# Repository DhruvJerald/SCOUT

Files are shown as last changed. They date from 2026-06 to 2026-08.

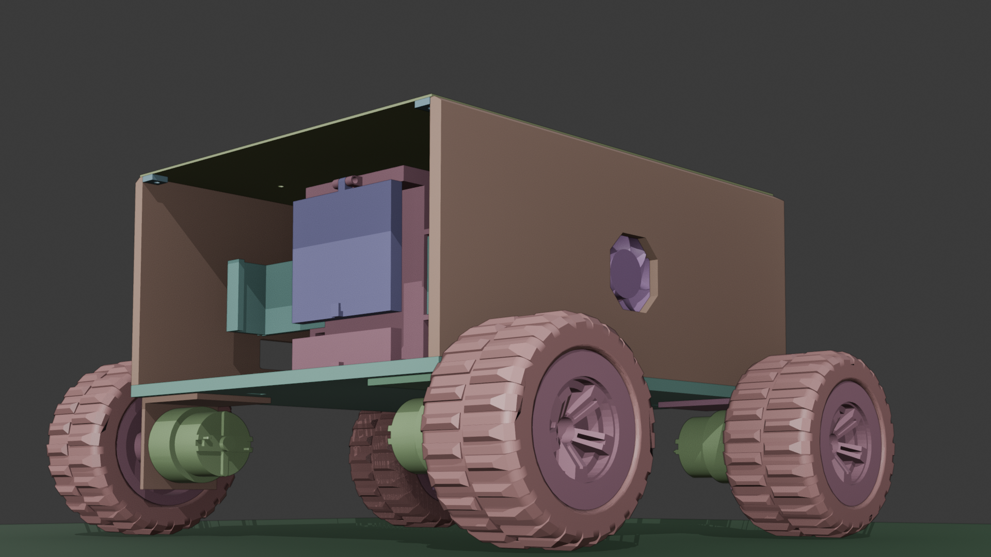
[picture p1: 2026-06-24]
BLENDER/rover.png

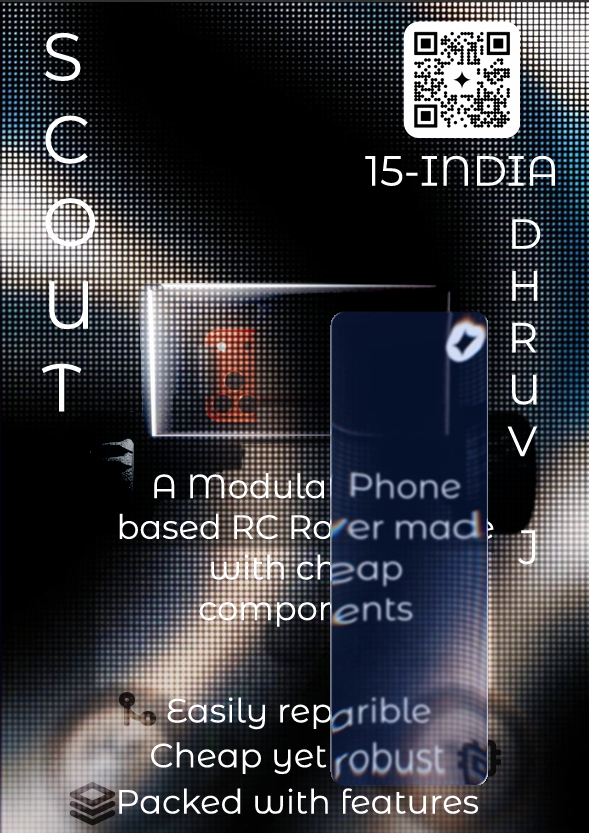
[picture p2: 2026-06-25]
Zine/Zine.png

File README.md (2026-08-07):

<div align="center">

# SCOUT
rover-removebg-preview

**A Rover built from cheap and easily available parts**

---

rover render

</div>

---

## What is it?

It's a RC rover that can be controlled from nearly everywhere. The idea follows a phone mounted in the chassis that does the heavy lifting such as streaming video, providing GPS, accelerometer, gyroscope, and cellular data while the ESP32 handles motors, sensors, and near Realtime control.
The entire rover has M3 mounting holes all over and doesn't use and glues or zip ties to make the final project closer to a product than a mere prototype and also being 3D printed in PLA.

## Why did i make it?
I really liked the idea of using the phones IMU, Accelerometer, GPS, Cellular connectivity, Camera, Microphone, Speakers, Flashlight and the onboard CPU of a phone which is really compact and possess a lot of expensive features of a real rover which would cost a fortune to source individual parts and i wanted to build a rover at a fraction of the price

---

## Goals

- **Repairable first** — Should be easy to make changes(spacious), Should be easy to mount things (M3 mounts), Should allow for future additions (Future proof with additional GPIO extensions)
- **Phone as compute** — SIM, Camera, GPS, IMU, Microphone, Speaker, Display, Accelerometer (All from a cheap android)
- **Cheap and sourceable** — every component available on Amazon.in or Robu.in or can be salvaged from old electronics
- **Controllable from anywhere but maintain fastest connectivity** — (fastest connection is made) between WIFI-AP, 4G cellular and Bluetooth

---

---

## Design



---

## Schematic

schematic

---

## BOM 

## BOM  

| Item | Price (INR) | Price (USD) |
|---|---|---|
| ESP32 DevKit V1 | 409 | $4.40 |
| 7.4V 6000mAh 2S LiPo | 1199 | $12.70 |
| XT60 connector pair | 260 | $2.75 |
| Rocker switch | 45 | $0.48 |
| LM2596 buck converter | 98 | $1.04 |
| TB6612FNG × 2 | 249 | $2.64 |
| INA219 | 275 | $2.92 |
| SSD1306 OLED | 329 | $3.50 |
| 5V brushless fan | 180 | $1.91 |
| AO3400A MOSFET | 84 | $0.89 |
| Resistors (10kΩ + 100Ω) | 154 | $1.63 |
| Capacitors (1000µF + 100µF × 2 + 0.1µF × 2) | 247 | $2.61 |
| M3 screw kit | 360 | $3.81 |
| 12V 200RPM motors × 4 | 500 | $5.29 |
| DHT22 | 160 | $1.69 |
| JST-XH connectors | 109 | $1.15 |
| 18AWG silicone wire | 300 | $3.17 |
| 85mm wheels × 4 | 749 | $7.93 |
| M3 standoffs | 300 | $3.17 |
| Perfboard | 125 | $1.32 |
| Phone mount (rubber bands) | 150 | $1.59 |
| 2S LiPo charger | 676 | $7.16 |
| White PLA 1kg | 899 | $9.51 |
| **Total** | **~₹7,875** | **~$85** |

> Many of these :- capacitors, resistors, perfboard, fan, MOSFET — >can be salvaged from old electronics.

---

## Features
- Battery saver mode — shuts down OLED, Fan, other non crucial sensors
- live voltage, current, and power from INA219 
- temperature data to keep control of overheating within the rover 
- status display on SSD1306 OLED
- all telemetry streamed to PC/Phone dashboard (web dashboard)

**Expansion**

The chassis has mounting holes and an I2C header for adding modules without redesigning anything so any future extension can be connected to the extension port and the new code could be compiled to work with it

---
## Assembly instructions

1)Gather all components listed in the BOM and a Android device with a working SIM card with cellular connection

2)3D print all the parts from https://github.com/DhruvJerald/SCOUT/tree/956e7d2e782e086f435cfa4e5dd025103bdec9e7/3D%20Prints and assemble it with M3 screws 

3)Add the Perfboard and the Electronics to the enclosure with M3 standoffs

4)Wire it according to the schematic https://github.com/DhruvJerald/SCOUT/blob/956e7d2e782e086f435cfa4e5dd025103bdec9e7/Schematic_Rover.png

5)Upload the firmware to the ESP (Not current one as its AI made and purely for proof of concept and not to be used in the final build)

6)Set up VPS on PC side

7)run the code on both devices 

---

## Images



chassis render

second render

SIDE







---

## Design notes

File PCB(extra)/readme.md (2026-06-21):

well uhh i idk why i created a pcb for it for no reason dont ask why i didnt i think of a perfboard or a mount earlier because thats what i ended up doing

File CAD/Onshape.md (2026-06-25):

Onshape Project link:- https://cad.onshape.com/documents/bb327acbee40f2ee69b4a73d/w/27bea1cc711a9dabe8ca095b/e/9c1c2f5421d70ceec33e618a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

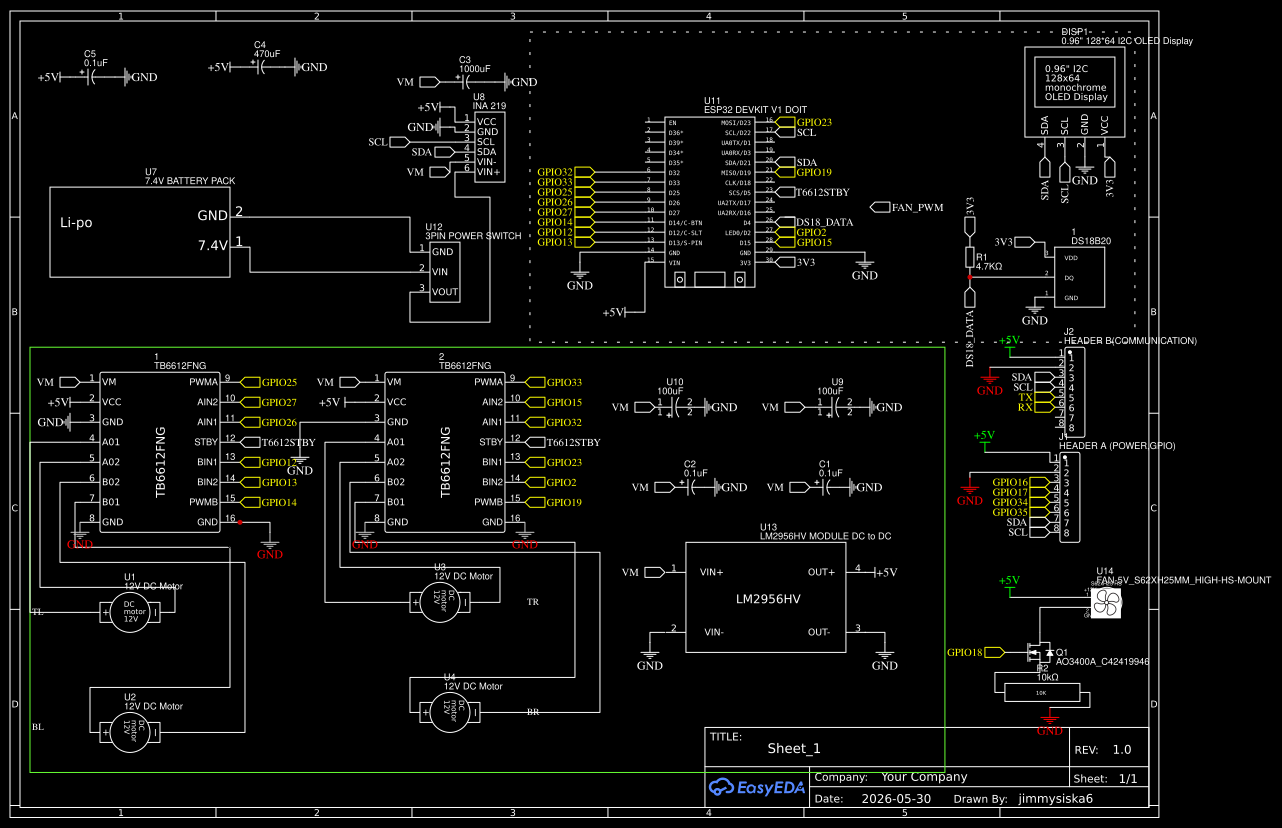
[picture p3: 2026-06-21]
Schematic_Rover.png

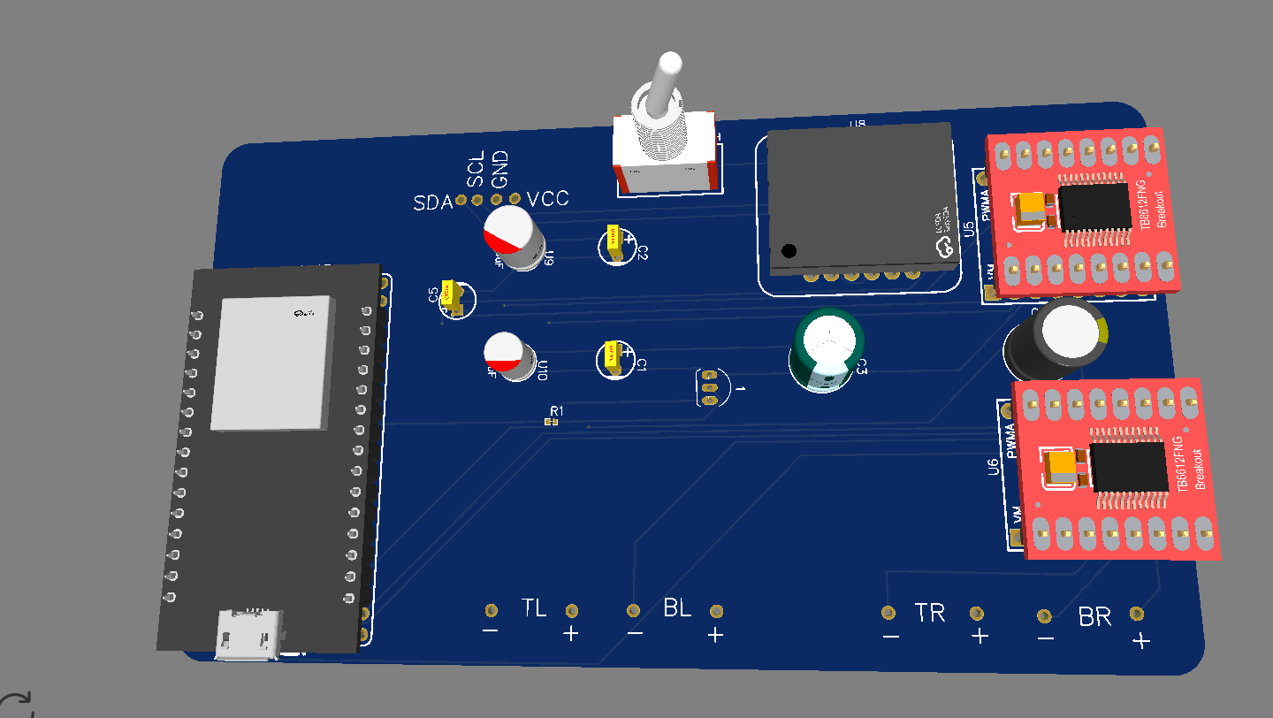
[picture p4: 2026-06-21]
PCB(extra)/Screenshot 2026-05-31 172008.png

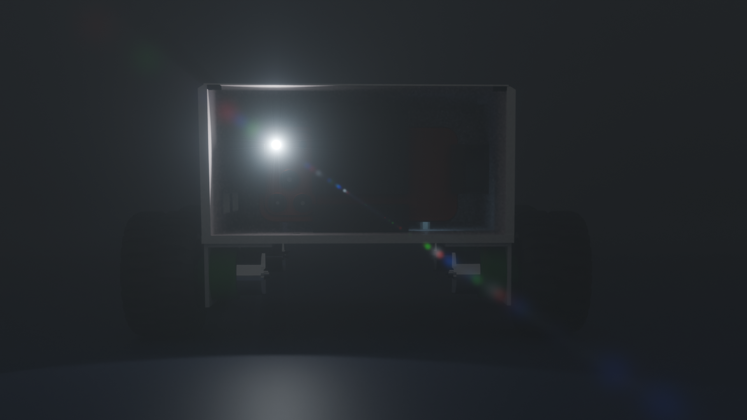
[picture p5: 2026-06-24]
BLENDER/Front view.png

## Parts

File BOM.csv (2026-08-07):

Category | Item | Qty | Notes/Specs | Seller Link | Price (INR) | Price (USD)
Main Controller | ESP32 DevKit V1 | 1 | DevKit V1 | https://robu.in/product/esp-wroom-32-wifi-bluetooth-networking-smart-component-development-board/ | ₹409 | $4.40
Power | 7.4V 6000mAh 2S LiPo | 1 | With BMS | https://robu.in/product/pro-range-nmc-18650-7-4v-6000mah-3c-2s2p-li-ion-battery-pack/ | ₹1199 | $12.70
Power | XT60 connector pair | 1 | Male+Female | https://www.amazon.in/Robocraze-XT60-Connector-Pair/dp/B07Q7VZ716/ | ₹260 | $2.75
Power | Rocker switch ≥5A | 1 | Toggle type | https://www.amazon.in/Rocker-Switch-Toggle-Plastic-Electronics/dp/B0GWS1MJB6/ | ₹45 | $0.48
Power | LM2596 Buck Converter | 1 | 7.4V→5V | https://www.amazon.in/LM2596-DC-DC-Buck-Converter-Module/dp/B009P04YTO/ | ₹98 | $1.04
Motor Drivers | TB6612FNG | 2 | Dual driver | Robu Services | ₹249 | $2.64
Monitoring | INA219 | 1 | Current sensor | https://www.amazon.in/xcluma-INA219-I2C-Bi-Directional/dp/B07YNQSLKX/ | ₹275 | $2.92
Monitoring | SSD1306 OLED 0.96 inch | 1 | I2C OLED | https://www.amazon.in/Robocraze-Semiconductor-Accessory-Display/dp/B07Q7VZ716/ | ₹329 | $3.50
Cooling | 5V brushless fan (30–40mm) | 1 | Exhaust fan | https://www.amazon.in/Electronic-Spices-40x40x10mm-Brushless-Exhaust/dp/B0BC8FLML8/ | ₹180 | $1.91
Cooling | AO3400A MOSFET | 1 | Logic-level | https://www.amazon.in/AO3400-30V-5-8A-N-Channel-Mosfet/dp/B09VH1K4GW/ | ₹84 | $0.89
Cooling | 10kΩ resistor | 1 | Gate pulldown | https://www.amazon.in/10K-ohm-Watt-Resistor-Tolerance/dp/B09VH1K4GW/ | ₹74 | $0.78
Capacitors | 1000µF 16V electrolytic | 1 | Main rail | https://www.amazon.in/gp/product/B08X2PGPPV/ | ₹89 | $0.94
Capacitors | 100µF 16V electrolytic | 2 | TB6612 rails | https://www.amazon.in/100uF-16V-Electrolytic-Capacitor/dp/B0F5MYTYQ3/ | ₹79 | $0.83
Capacitors | 0.1µF ceramic | 2 | TB6612 rails | https://www.amazon.in/0-1uF-104-Ceramic-Capacitor-Pack/dp/B0F5MYTYQ3/ | ₹79 | $0.83
Hardware | M3 Screw Kit | 1 set | Assorted sizes | https://www.amazon.in/gp/product/B0FQWLQMXV/ | ₹360 | $3.81
DRIVE | 12V geared DC Motor | 4 | 12V 200 RPM | https://www.amazon.in/D-V-12V-200-RPM-Geared-Motor/dp/B07YNQSLKX/ | ₹500 | $5.29
Cooling | DHT22 temp+humidity sensor | 1 | Fan controls | https://www.amazon.in/AM2302-Temperature-Humidity-Sensor-Module/dp/B0CXMJH34D/ | ₹160 | $1.69
Resistors | 100Ω resistor | 1 | Pull-up | https://www.amazon.in/100-Ohm-Resistor-Pack/dp/B09VH1K4GW/ | ₹80 | $0.85
Wires | JST-XH connectors | 4 | Battery connectors | https://www.amazon.in/Electronic-Spices-Connector-2-5mm-Female/dp/B0BKWDKB1W/ | ₹109 | $1.15
Wires | 18AWG silicone wire | 1m | High durability | https://www.amazon.in/gp/product/B09VLDN5LN/ | ₹300 | $3.17
DRIVE | 85mm Wheels | 4 | Wheels | https://www.amazon.in/INVENTO-Plastic-Robotic-Durable-Rubber/dp/B07YNQSLKX/ | ₹749 | $7.93
Hardware | M3 standoffs | 20 | Standoffs | https://www.amazon.in/gp/product/B07T34Q6G6/ | ₹300 | $3.17
Hardware | 12×8 Perfboard | 1 | Prototype board | https://www.amazon.in/xcluma-Double-Copper-Prototype-Universal/dp/B073DF2CB9/ | ₹125 | $1.32
Phone Mount | Rubber Bands | 3 | Holds phone | https://www.amazon.in/cart/smart-wagon/ | ₹150 | $1.59
Charger | 2S Li-ion charger | 1 | For battery | https://robu.in/product/lithium-battery-charger-8-4v-1a-with-dc-plug-2-indicators/ | ₹676 | $7.16
Chassis | White PLA 1kg | 1 | Printed for chassis | https://www.amazon.in/WOL-3D-Filament-Improved-Formula/dp/B08D6N1HHK/ | ₹899 | $9.51
TOTAL |  |  |  |  | ₹7857 | $85

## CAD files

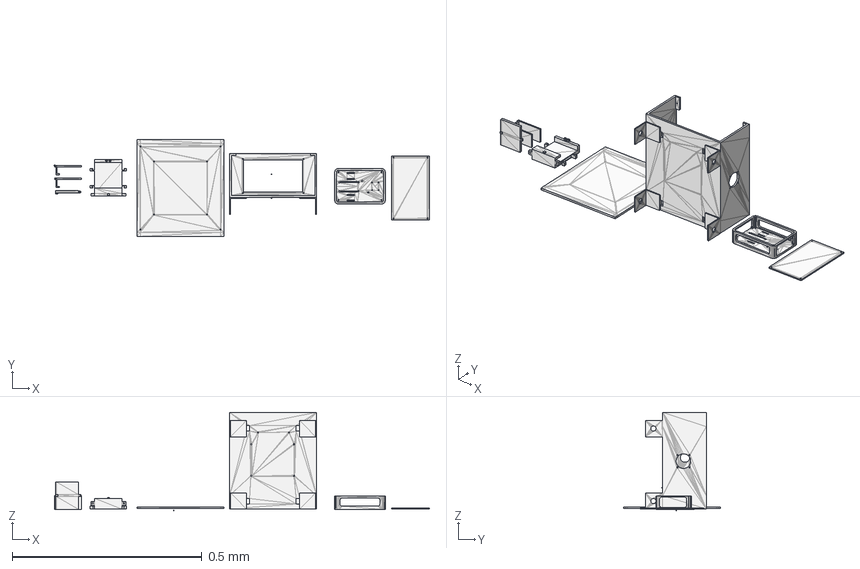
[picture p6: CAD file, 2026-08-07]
3D Prints/CHASIS.step
0.989 x 0.255 x 0.26 mm

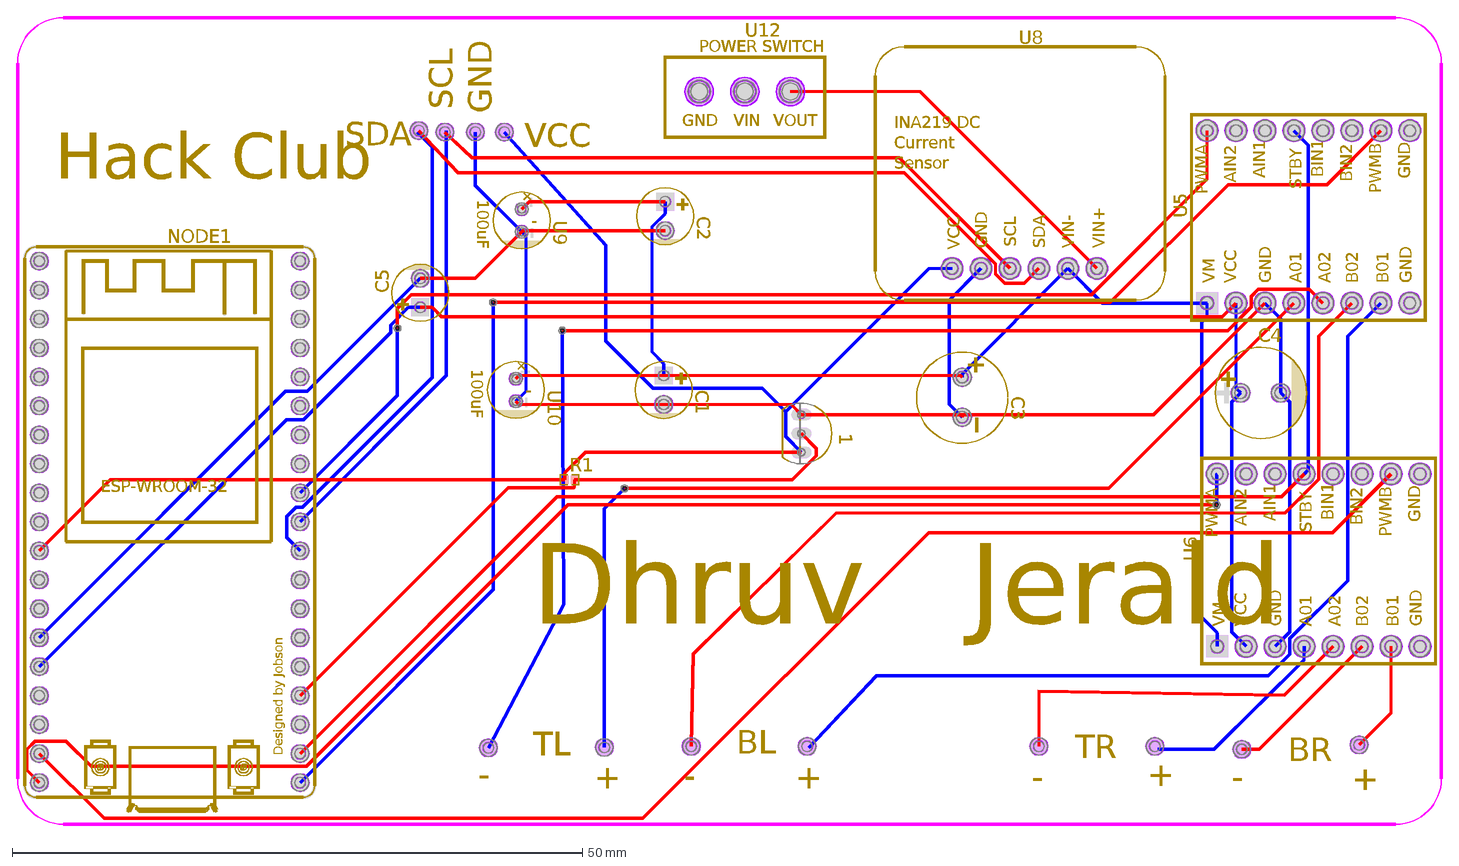
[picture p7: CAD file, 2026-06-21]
PCB(extra)/PCB_Rover-Scheme1_2026-06-01.dxf
BR
TR
BL
TL
+
-
VCC
SDA
GND
SCL
Hack Club
Dhruv Jerald
1
NODE1
ESP-WROOM-32
Designed by Jobson
R1
U5
B02
A02
VM
PWMA
AIN2
AIN1
STBY
BIN1
BIN2
PWMB
B01
A01
U6
U8
VIN+
VIN-
INA219 DC
Current
Sensor
U9
100uF
U10
U12
VIN
VOUT
POWER SWITCH
C1
C2
C5
C3
C4

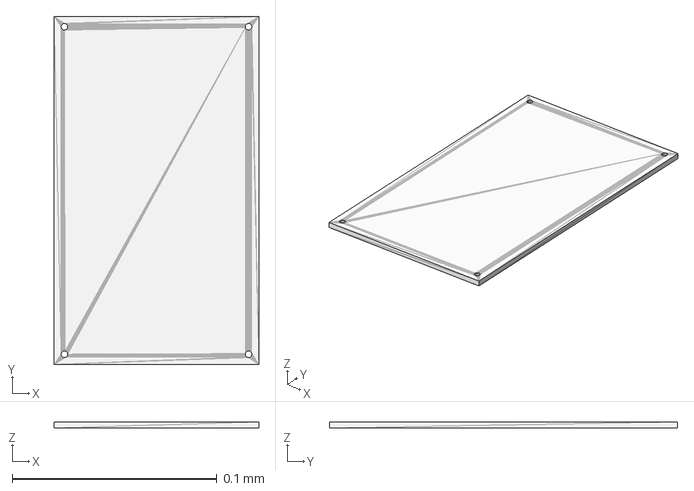
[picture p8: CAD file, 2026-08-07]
3D Prints/BACKPLATE (TP).step
0.1 x 0.17 x 0.003 mm

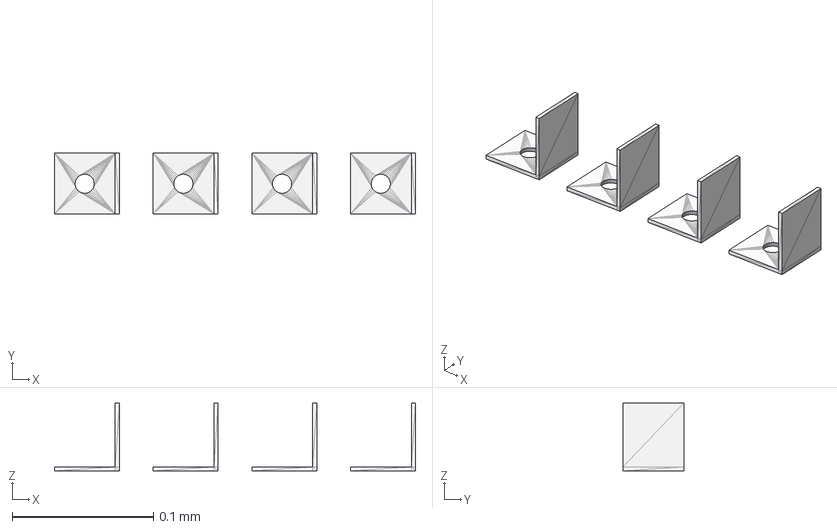
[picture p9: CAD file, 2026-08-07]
3D Prints/MOTOR MOUNTS.step
0.256 x 0.0431 x 0.0482 mm

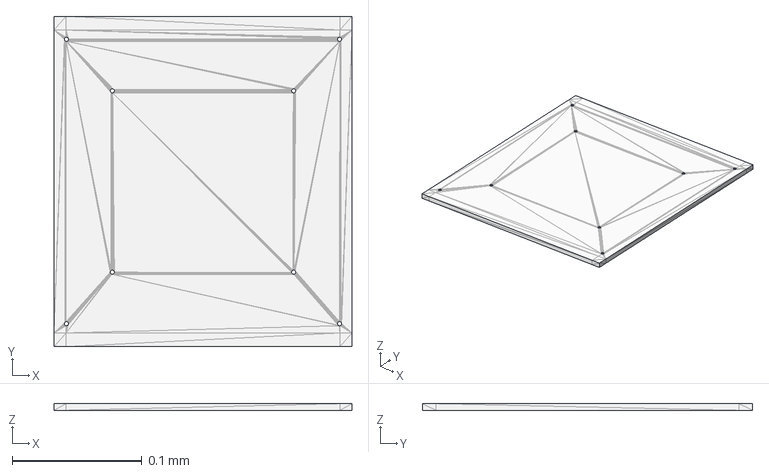
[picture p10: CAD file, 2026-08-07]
3D Prints/ROOF.step
0.23 x 0.255 x 0.00512 mm

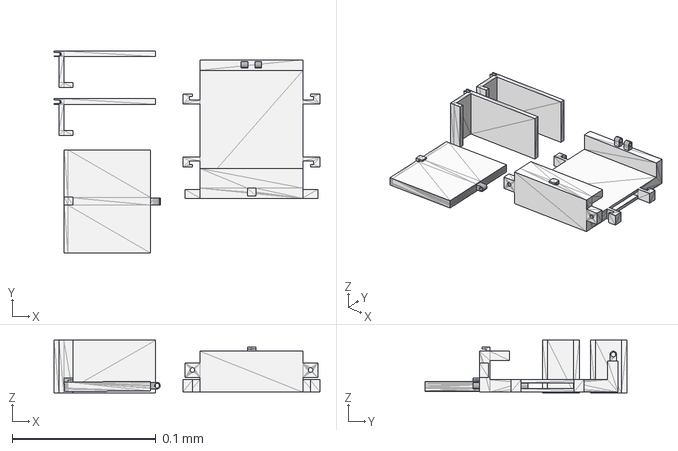
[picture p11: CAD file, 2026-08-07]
3D Prints/PHONE MOUNTS.step
0.185 x 0.14 x 0.0366 mm

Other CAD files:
3D Prints/BACKPLATE (TP).stl
3D Prints/CHASIS.stl
3D Prints/MOTOR MOUNTS.stl
3D Prints/PHONE MOUNTS.stl
3D Prints/ROOF.stl

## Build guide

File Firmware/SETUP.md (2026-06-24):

THIS FIRMWARE ISNT TESTED YET

# SCOUT SETUP FILE

---

## Contents

1. System Architecture
2. Hardware Architecture
3. Power Architecture
4. Pin Assignment and Wiring
5. Transport Layer Architecture
6. Software Architecture
7. Firmware Setup (ESP32)
8. Phone Dashboard Setup
9. VPS Relay Setup
10. Battery Saver Mode
11. Communication Protocol Reference
12. Build and Test Sequence
13. Fault Diagnosis

---

## 1. System Architecture

The system has three physical nodes. Every command and every telemetry reading
travels through all three in sequence.

```
+------------------+        internet         +------------------+
|    PC (home)     |  <--------------------> |   VPS (cloud)    |
|                  |     WebSocket / HTTPS   |   cloud_relay.js |
|  Browser opens   |                         |   public IP      |
|  phone/index.html|                         |  Node.js server  |
+------------------+                         +--------+---------+
                                                      |
                                                   4G / WiFi
                                                      |
                                             +--------v---------+
                                             |  Phone (on rover)|
                                             |  Chrome browser  |
                                             |  index.html      |
                                             |                  |
                                             |  Holds TWO       |
                                             |  connections:    |
                                             |  1. outward VPS  |
                                             |  2. inward ESP32 |
                                             +--------+---------+
                                                      |
                                          BLE or WiFi (last mile)
                                                      |
                                             +--------v---------+
                                             |  ESP32 (rover)   |
                                             |  BLE UART server |
                                             |  WiFi AP server  |
                                             |  WebSocket server|
                                             +--------+---------+
                                                      |
                                              GPIO pins (wires)
                                                      |
                              +-----------+-----------+-----------+
                              |           |           |           |
                        +-----v----+ +----v----+ +----v---+ +----v----+
                        | TB6612 1 | |TB6612 2 | | INA219 | |DS18B20 |
                        | L motors | |R motors | | power  | | temp   |
                        +-----+----+ +----+----+ +--------+ +--------+
                              |           |
                       +------+    +------+
                       |           |
                  +----v----+ +----v----+
                  |LF motor | |RF motor |
                  |LR motor | |RR motor |
                  +---------+ +---------+
```

The phone is the bridge. It is physically mounted on the rover and runs the
browser app. It maintains one connection outward (to VPS or PC) and one
connection inward (to ESP32 via BLE or WiFi). When you push the joystick on
your PC, the command travels: PC -> VPS -> phone -> ESP32 -> motors.

When the phone and rover are close to your PC on the same network, the VPS
is bypassed entirely. When the phone is within 10m of the ESP32 and BLE is
available, WiFi is bypassed as well. The system always takes the shortest path.

---

## 2. Hardware Architecture

```
                    ROVER PHYSICAL LAYOUT (top view)
    +-------------------------------------------------------+
    |  [OLED display]                    [Expansion header] |
    |                                                        |
    |   +---------------+     +---------------+             |
    |   |   TB6612 #1   |     |   TB6612 #2   |             |
    |   |  (left side)  |     |  (right side) |             |
    |   +---+-----------+     +----------+----+             |
    |       |                            |                   |
    |  LF--LR                        RF--RR                 |
    |  motors                        motors                  |
    |                                                        |
    |   +---------------------------+                        |
    |   |       ESP32 DevKit V1     |   [INA219]             |
    |   |                           |   [DS18B20]            |
    |   +---------------------------+                        |
    |                                                        |
    |   [Fan + AO3400 MOSFET]          [Power switch]        |
    |                                                        |
    |   +---------------------------+                        |
    |   |  2x 18650 cells + 2S BMS |                        |
    |   +---------------------------+                        |
    +-------------------------------------------------------+
    [LF wheel]  [LR wheel]           [RF wheel]  [RR wheel]

    LAYER STACK (electronics, bottom to top)

    Bottom plate:  4 motors, wheels, motor mounts
    Middle plate:  18650 cells, BMS, power switch, INA219
    Top plate:     ESP32, TB6612 x2, DS18B20, fan
    Roof rail:     OLED, expansion header, phone mount
```

---

## 3. Power Architecture

The INA219 sits in series on the positive rail so it measures total current
drawn by the entire system. The LM2596 buck converter steps 7.4V down to 5V
for the ESP32 and logic. The TB6612 drivers receive the raw battery voltage
directly as their motor supply.

```
  2x 18650 cells (7.4V nominal, 8.4V full, 6.0V cutoff)
         |
         |  positive rail
         v
     [2S BMS]  <-- cuts off if cell < 3.0V or current > rated limit
         |
         v
    [1N5408 diode]  <-- reverse polarity protection, 0.6V drop
         |
         v
     [3A fuse]  <-- overcurrent protection (motor short circuit)
         |
         v
  [Power switch]
         |
         +---------------------------+
         |                           |
         v                           v
     [INA219]                  [LM2596 buck]
    VIN+ to VIN-               7.4V --> 5V
    measures all                    |
    system current                  +----------+----------+
         |                          |          |          |
         v                          v          v          v
    [TB6612 VM]               [ESP32 VIN]  [OLED VCC]  [Fan 5V]
    raw 7.4V for                3.3V reg    (3.3V)     (5V)
    motors                      onboard
         |
    +----+----+
    |         |
    v         v
 [TB6612 #1] [TB6612 #2]
 LF + LR     RF + RR
 motors      motors

  VOLTAGE AT EACH POINT (measure with multimeter to verify)

  Point                    Expected range      If wrong
  -------                  --------------      --------
  Battery terminals        6.0 - 8.4V          BMS tripped or dead cells
  After diode              0.6V less than bat   Diode missing or reversed
  After fuse               same as post-diode   Fuse blown
  INA219 VIN+ to VIN-      < 0.1V (shunt drop) INA219 bypassed (wrong wire)
  TB6612 VM                same as post-fuse    Break in motor supply wire
  LM2596 output            4.8 - 5.2V          Buck not adjusted or failed
  ESP32 VIN                4.8 - 5.2V          Wire break to ESP32
  ESP32 3.3V pin           3.1 - 3.4V          ESP32 internal reg failed
```

### Current budget

```
  Component                Idle      Active (peak)
  ---------                ----      -------------
  ESP32 (WiFi active)      150mA     350mA
  ESP32 (BLE only)          30mA      80mA
  OLED SSD1306              20mA      20mA
  INA219                     1mA       1mA
  DS18B20                    1mA       1mA
  Fan (5V, small)             0mA     200mA
  4x TT motors (idle)        20mA      20mA
  4x TT motors (running)       --     800mA
  4x TT motors (stall)         --    2000mA
  -------------------------------------------------------
  Normal mode total          200mA   ~2600mA peak
  Battery saver total         50mA   ~2100mA (motors only)

  Runtime estimate (5000mAh 2S LiPo):
    Driving normally:  ~1.5 - 2.5 hours
    Battery saver idle:  ~50 hours (BLE connected, stationary)
```

---

## 4. Pin Assignment and Wiring

### ESP32 DevKit V1 pinout map

Only the pins used in this project are labeled. Blank pins are free for
expansion unless marked NEVER USE.

```
                    ESP32 DevKit V1 (38-pin)
                    +=========================+
               3.3V |  1                  38 | GND
              RESET |  2                  37 | GPIO23  --> R_F_PWMA  (LEDC ch2)
    NEVER  --> GND  |  3                  36 | GPIO22  --> I2C SCL
    USE         5V  |  4                  35 | GPIO21  --> I2C SDA
                    |  5                  34 | GPIO19  --> R_R_BIN1
   INPUT      GPIO34|  6                  33 | GPIO18  --> R_R_PWMB  (LEDC ch3)
   ONLY       GPIO35|  7                  32 | GPIO5   --> R_R_BIN2
   (no        GPIO32|  8 --> R_F_AIN1    31 | GPIO17  RESERVED TX2
   pullup)    GPIO33|  9 --> TB6612 STBY 30 | GPIO16  RESERVED RX2
              GPIO25| 10 --> L_F_AIN1    29 | GPIO4   --> DS18B20 data
              GPIO26| 11 --> L_F_AIN2    28 | GPIO2   --> R_F_AIN2
              GPIO27| 12 --> L_F_PWMA    27 | GPIO15  --> Fan gate
              GPIO14| 13 --> L_R_BIN1    26 | GPIO13  --> L_R_PWMB  (LEDC ch1)
              GPIO12| 14 --> L_R_BIN2    25 | GPIO12  already used (left)
    NEVER  --> GND  | 15                  24 | GND
    USE    --> 3.3V | 16                  23 | 5V (from LM2596)
    GPIO6-11 FLASH  |  (internal, never break out)
                    +=========================+

    PINS TO NEVER USE:
    GPIO 0   -- Boot button. Pulling LOW during boot enters flash mode.
    GPIO 1   -- UART TX (USB serial debug output)
    GPIO 3   -- UART RX (USB serial debug input)
    GPIO 6-11-- Connected to internal flash memory. Using these destroys flash.
    GPIO34-39-- INPUT ONLY. No internal pull-up. Cannot drive anything.

    RESERVED (do not assign):
    GPIO16   -- Future UART2 RX (GPS module)
    GPIO17   -- Future UART2 TX (GPS module)
```

### Full wiring table

```
  ESP32 GPIO   Direction   Connects to           Notes
  ----------   ---------   -----------           -----
  GPIO2        OUT         TB6612#2 AIN2         R Front motor dir B
  GPIO4        IN          DS18B20 DATA          4.7k pullup to 3.3V required
  GPIO5        OUT         TB6612#2 BIN2         R Rear motor dir B
  GPIO12       OUT         TB6612#1 BIN2         L Rear motor dir B
  GPIO13       OUT(PWM)    TB6612#1 PWMB         L Rear speed, LEDC ch1
  GPIO14       OUT         TB6612#1 BIN1         L Rear motor dir A
  GPIO15       OUT         AO3400 gate           Fan MOSFET, 100R series + 10k pulldown
  GPIO18       OUT(PWM)    TB6612#2 PWMB         R Rear speed, LEDC ch3
  GPIO19       OUT         TB6612#2 BIN1         R Rear motor dir A
  GPIO21       IN/OUT      SDA bus               INA219 + OLED shared, 4.7k pullup
  GPIO22       IN/OUT      SCL bus               INA219 + OLED shared, 4.7k pullup
  GPIO23       OUT(PWM)    TB6612#2 PWMA         R Front speed, LEDC ch2
  GPIO25       OUT         TB6612#1 AIN1         L Front motor dir A
  GPIO26       OUT         TB6612#1 AIN2         L Front motor dir B
  GPIO27       OUT(PWM)    TB6612#1 PWMA         L Front speed, LEDC ch0
  GPIO32       OUT         TB6612#2 AIN1         R Front motor dir A
  GPIO33       OUT         TB6612#1 STBY         Shared STBY for both TB6612s
```

### TB6612 motor driver wiring (per chip)

Each TB6612 has two independent H-bridge channels (A and B), each driving
one motor. The chip needs 3 pins per motor (direction A, direction B, PWM)
plus one shared STBY pin.

```
  TB6612 #1 (left side)          TB6612 #2 (right side)
  +-----------------+            +-----------------+
  | VM   --> bat+   |            | VM   --> bat+   |
  | GND  --> GND    |            | GND  --> GND    |
  | VCC  --> 3.3V   |            | VCC  --> 3.3V   |
  | STBY --> GPIO33 |            | STBY --> GPIO33 |  (shared)
  |                 |            |                 |
  | AIN1 --> GPIO25 |            | AIN1 --> GPIO32 |
  | AIN2 --> GPIO26 |            | AIN2 --> GPIO2  |
  | PWMA --> GPIO27 |            | PWMA --> GPIO23 |
  | AO1  --> LF+    |            | AO1  --> RF+    |
  | AO2  --> LF-    |            | AO2  --> RF-    |
  |                 |            |                 |
  | BIN1 --> GPIO14 |            | BIN1 --> GPIO19 |
  | BIN2 --> GPIO12 |            | BIN2 --> GPIO5  |
  | PWMB --> GPIO13 |            | PWMB --> GPIO18 |
  | BO1  --> LR+    |            | BO1  --> RR+    |
  | BO2  --> LR-    |            | BO2  --> RR-    |
  +-----------------+            +-----------------+

  Motor direction truth table (same for all four motors):
  IN1    IN2    PWM    Result
  HIGH   LOW    0-255  Forward (speed proportional to PWM)
  LOW    HIGH   0-255  Reverse
  HIGH   HIGH   any    Active brake (motor shorted, decelerates fast)
  LOW    LOW    any    Coast (motor free-spinning)
```

### Fan MOSFET wiring

```
  5V rail ----+
              |
           [Fan +]
           [Fan -]
              |
           [Drain]
           AO3400
           [Gate] <---- [100R resistor] <---- GPIO15
           [Source]
              |
           [GND] <---- [10k resistor] <---- also [Gate]
                        (pull-down)

  The 10k from gate to GND ensures GPIO15 is LOW at boot.
  GPIO15 has an internal pull-up that could turn the fan on during boot.
  The external 10k overrides it. Without this resistor, fan may
  briefly switch on every time the ESP32 resets.
```

### I2C bus wiring

Both INA219 and SSD1306 OLED share the same two wires. Pull-up resistors
are needed once on the bus, not once per device.

```
  ESP32 3.3V ----+----+
                 |    |
               4.7k  4.7k   (one pair for the entire I2C bus)
                 |    |
  GPIO21 (SDA) --+--+-+--+------ INA219 SDA
                    |            SSD1306 SDA
  GPIO22 (SCL) -----+--+-------- INA219 SCL
                       |         SSD1306 SCL

  I2C addresses:
    INA219:   0x40 (default, pins A0 A1 both GND)
    SSD1306:  0x3C (most common) or 0x3D (some modules)
    Firmware tries 0x3C first, falls back to 0x3D automatically.

  To scan for addresses: upload i2c_scanner.ino (Arduino IDE examples)
  before wiring sensors. Any device found at an unexpected address
  means a different module variant.
```

---

## 5. Transport Layer Architecture

The system supports three transport paths. They are not exclusive: BLE and
WiFi run simultaneously on the ESP32 at all times (when in normal mode).
The phone decides which one to use for the current command.

```
  TRANSPORT COMPARISON

  Property          BLE                WiFi AP           4G Relay
  --------          ---                -------           --------
  Range             ~10m               ~50m open air     unlimited
  Latency           20 - 80ms          5 - 20ms          50 - 250ms
  Power (ESP32)     30 - 50mA          200 - 300mA       200 - 300mA
  Requires router   no                 no                VPS + internet
  iOS support       no (Apple blocked) yes               yes
  Android Chrome    yes                yes               yes
  When to use       close range, saver normal operation  remote control

  SELECTION LOGIC (runs in phone browser JavaScript)

  On connect:
  1. Does browser support Web Bluetooth?
       NO  --> skip to step 3
       YES --> try BLE scan for "MSRP1-Rover"
  2. BLE found?
       NO  --> try step 3
       YES --> connect BLE, use as primary transport
  3. Try WebSocket to ws://192.168.4.1/ws (ESP32 AP)
       SUCCESS --> use WiFi as transport
       FAIL    --> try step 4
  4. Is relay URL configured?
       NO  --> show "not connected" error
       YES --> connect to VPS WebSocket (wss://VPS_IP:8081/?role=phone)
               phone bridges VPS <-> ESP32 (BLE or WiFi, whichever works)

  If active transport drops:
       BLE drops  --> immediately try WiFi path
       WiFi drops --> immediately try 4G relay path
       All drop   --> motor watchdog fires after 500ms, motors stop

  DATA FLOW: DRIVE COMMAND (PC to motors)

  PC browser                 VPS                 Phone browser
  ----------                 ---                 -------------
  user moves joystick
  |
  v
  JSON: {type:"drive",       ----websocket--->   receives command
         left:180,right:180}                     |
                                                 v
                                                 (which transport is active?)
                                                  |
                             +---BLE path---------+---WiFi path----------+
                             |                                            |
                             v                                            v
                      BLE UART write                           WebSocket send
                      to ESP32 RX char                         to 192.168.4.1/ws
                             |                                            |
                             +--------------------+------------------------+
                                                  |
                                                  v
                                           processCommand()
                                           updates g_cmd struct
                                                  |
                                           taskMotorController
                                           reads g_cmd at 100Hz
                                                  |
                                           setMotors(left, right)
                                                  |
                                           TB6612 drives motors

  DATA FLOW: TELEMETRY (rover to PC)

  ESP32 taskTelemetry (10Hz)
  |
  +-- reads INA219 (voltage, current, power)
  +-- reads DS18B20 (temperature)
  |
  v
  builds JSON string in stack buffer (no heap allocation)
  |
  +-- if WiFi clients connected: ws.textAll(buffer)
  +-- if BLE client connected:   bleTxChar->notify(buffer)
  |
  v
  Phone browser receives on whichever transport it used
  |
  +-- if in relay mode: forward to VPS websocket
  |
  v
  VPS forwards to PC browser
  |
  v
  PC browser updates telemetry display
```

---

## 6. Software Architecture

### Firmware task layout (FreeRTOS)

The ESP32 runs four concurrent tasks. Tasks on Core 1 are time-critical.
Tasks on Core 0 can tolerate occasional delays from WiFi/BLE interrupts.

```
  Core 1 (time-critical)         Core 0 (background)
  ----------------------         -------------------
  taskMotorController            taskTelemetry
  priority 5 (highest)           priority 3
  period: 10ms (100Hz)           period: 100ms (10Hz)
  stack: 4096 bytes              stack: 5120 bytes
  |                              |
  reads g_cmd (mutex)            reads INA219, DS18B20
  applies dead zone (+/-10)      writes g_telem (mutex)
  applies watchdog (500ms)       broadcasts JSON via WiFi + BLE
  calls setMotors()              checks auto battery saver
                                 |
                                 taskFanController
                                 priority 2
                                 period: 1000ms (1Hz)
                                 stack: 2048 bytes
                                 |
                                 hysteresis: on@40C, off@35C
                                 disabled in battery saver mode
                                 |
                                 taskOLED
                                 priority 1 (lowest)
                                 period: 500ms (2Hz)
                                 stack: 4096 bytes
                                 |
                                 renders: transport, voltage,
                                 current, temp, fan, battery bar
                                 skipped in battery saver mode

  SHARED DATA PROTECTION

  g_cmd struct (left, right speeds):
    written by: WebSocket handler, BLE RX callback
    read by:    taskMotorController
    protected:  cmdMutex (FreeRTOS mutex)

  g_telem struct (voltage, current, temp, fan, clients):
    written by: taskTelemetry, taskFanController
    read by:    taskOLED, HTTP status endpoint
    protected:  telemMutex (FreeRTOS mutex)

  g_powerMode (POWER_NORMAL / POWER_SAVER):
    written by: processCommand(), taskTelemetry (auto)
    read by:    taskFanController, taskOLED, taskTelemetry
    type:       volatile enum (no mutex, single-word atomic write)

  COMMAND PROCESSING PATH

  WebSocket onWsEvent()                BLE BLERxCallbacks::onWrite()
       |                                        |
       v                                        v
  data[len] = 0   (null terminate)    chr->getValue() (std::string)
       |                                        |
       +------------------+--------------------+
                          |
                          v
                  processCommand(json, transport_source)
                          |
                  deserializeJson() via ArduinoJson
                          |
             +------------+------------+
             |            |            |
          "drive"       "stop"       "power"
             |            |            |
        update g_cmd  zero g_cmd   set g_powerMode
        update        update        (saver/normal)
        g_lastCmdMs   g_lastCmdMs
        g_lastTransport
```

### File structure and what each file does

```
  rover-v3/
  |
  +-- esp32/
  |   +-- rover_v3_firmware.ino    Single .ino file, all firmware
  |                                 Flashed to ESP32 via Arduino IDE
  |                                 Contains: pin defs, tasks, BLE server,
  |                                 WebSocket server, embedded HTML fallback
  |
  +-- phone/
  |   +-- index.html               Single HTML file, no build step
  |                                 Opened in Chrome Android on phone
  |                                 Contains: transport manager, joystick,
  |                                 BLE via Web Bluetooth API,
  |                                 WiFi via WebSocket API,
  |                                 camera via getUserMedia API,
  |                                 GPS via Geolocation API,
  |                                 IMU via DeviceOrientation API
  |
  +-- server/
  |   +-- cloud_relay.js           Node.js server, runs on VPS
  |   +-- package.json             npm dependencies: ws, express
  |
  +-- SETUP_V3.md                  This file
```

---

## 7. Firmware Setup (ESP32)

### 7.1 Install Arduino IDE and ESP32 board support

Download Arduino IDE 2.x from arduino.cc. Open File -> Preferences and add
this URL to "Additional boards manager URLs":

```
https://raw.githubusercontent.com/espressif/arduino-esp32/gh-pages/package_esp32_index.json
```

Go to Tools -> Board -> Boards Manager. Search "esp32". Install
"esp32 by Espressif Systems" version 2.x or later.

### 7.2 Install required libraries

Tools -> Manage Libraries. Search and install each:

```
  Library name (search exactly)    Author              Purpose
  -----------------------------    ------              -------
  NimBLE-Arduino                   h2zero              BLE server (NEW in V3)
  ESPAsyncWebServer                lacamera            HTTP + WebSocket server
  AsyncTCP                         dvarrel             Required by above
  Adafruit SSD1306                 Adafruit            OLED display driver
  Adafruit GFX Library             Adafruit            Required by above
  Adafruit INA219                  Adafruit            Voltage/current sensor
  DallasTemperature                Miles Burton        DS18B20 temperature
  OneWire                          Paul Stoffregen     Required by above
  ArduinoJson                      Benoit Blanchon     JSON parse and build

  Note: ESPAsyncWebServer and AsyncTCP may not appear in Library Manager.
  If not found, download as ZIP from GitHub and install via:
  Sketch -> Include Library -> Add .ZIP Library

  ESPAsyncWebServer: https://github.com/lacamera/ESPAsyncWebServer
  AsyncTCP:          https://github.com/dvarrel/AsyncTCP
```

### 7.3 Board settings

```
  Setting              Value
  -------              -----
  Board                ESP32 Dev Module
  Upload Speed         921600
  CPU Frequency        240 MHz
  Flash Frequency      80 MHz
  Flash Mode           QIO
  Flash Size           4MB (32Mb)
  Partition Scheme     Default 4MB with spiffs
  Core Debug Level     None
  Port                 COMx (Windows) or /dev/ttyUSB0 (Linux/Mac)
```

### 7.4 Flash procedure

1. Open rover_v3_firmware.ino in Arduino IDE
2. Select correct board and port (Tools menu)
3. Click Upload (right arrow button)
4. If upload fails with "Failed to connect": hold the BOOT button on the
   ESP32 while clicking Upload, release after "Connecting..." appears

### 7.5 Verify boot via Serial Monitor

Open Tools -> Serial Monitor. Set baud rate to 115200. Press the RST button
on the ESP32. You must see all of these lines in order:

```
  [BOOT] MSRP-1 V3 starting...
  [BOOT] Motor drivers enabled
  [BOOT] OLED OK
  [BOOT] INA219 OK
  [BOOT] DS18B20 OK (1 sensor)
  [BOOT] BLE advertising as 'MSRP1-Rover'
  [BOOT] WiFi AP: SSID='ROVER-V3'  IP=192.168.4.1
  [BOOT] HTTP + WebSocket server on port 80
  [BOOT] All tasks started. Rover ready.
  [BOOT] Transports: BLE (primary) + WiFi AP (secondary)

  If any [WARN] lines appear:
  [WARN] OLED not found at 0x3C, trying 0x3D...  -->  check SDA/SCL wiring + pullups
  [WARN] INA219 not found (0x40)                  -->  check I2C wiring
  [WARN] DS18B20 not found                        -->  check 4.7k pullup on GPIO4
```

---

## 8. Phone Dashboard Setup

### 8.1 Browser requirement

```
  Browser          BLE support   WiFi support   Recommended
  -------          -----------   ------------   -----------
  Chrome Android   YES           YES            PRIMARY CHOICE
  Firefox Android  no            YES            WiFi only
  Safari iOS       no            YES            WiFi only
  Chrome iOS       no            YES            Apple blocks BLE in all iOS browsers
  Chrome Desktop   YES*          YES            *requires HTTPS or localhost
```

### 8.2 Serving the dashboard to the phone

Option A — serve from PC on local network (easiest for development):

```
  On PC, in the rover-v3/phone/ folder, run:
    python3 -m http.server 8080

  On phone, open Chrome and go to:
    http://YOUR_PC_LAN_IP:8080

  Find your PC LAN IP:
    Windows:  ipconfig  (look for IPv4 Address under WiFi adapter)
    Linux:    ip addr   (look for inet under wlan0 or eth0)
    Mac:      ifconfig  (look for inet under en0)
```

Option B — serve from the rover itself (no PC needed):

```
  The ESP32 serves a minimal embedded dashboard at http://192.168.4.1
  This is the fallback. It has full joystick + telemetry + power controls.
  Connect phone to ROVER-V3 WiFi, then open 192.168.4.1 in any browser.
  Camera, GPS, and IMU are not available in the embedded version.
```

Option C — host index.html on VPS (for permanent remote access):

```
  Copy phone/index.html to your VPS web root:
    scp phone/index.html user@VPS_IP:/var/www/html/rover.html

  Access from anywhere at:
    http://VPS_IP/rover.html
```

### 8.3 First BLE connection (Chrome Android)

1. Open Chrome on Android. Go to Settings -> Site settings -> Bluetooth.
   Make sure it is allowed.
2. Open the dashboard URL.
3. Click "Connect BLE" button. Chrome shows a device picker.
4. Select "MSRP1-Rover" from the list.
5. Click Pair. The connection dot turns green.
6. Telemetry values start updating. Joystick now controls motors.

After the first pairing, subsequent connections are automatic. The browser
remembers the device and reconnects without showing the picker.

### 8.4 Transport mode switching

```
  Dashboard transport indicator states:

  "BLE" (green dot)   -- BLE active, lowest power, phone within ~10m
  "WiFi" (green dot)  -- WiFi WebSocket active, phone on ROVER-V3 network
  "Relay" (green dot) -- 4G relay active, VPS URL configured and connected
  "---" (red dot)     -- no transport active, motors will stop in 500ms

  Switching is automatic. To force a specific mode, use the mode buttons
  in the dashboard (DIRECT / LOCAL WiFi / RELAY).
```

---

## 9. VPS Relay Setup

The VPS relay is only needed for controlling the rover from home while the
rover is somewhere else on a phone data connection. Skip this section for
local operation.

### 9.1 VPS requirements

```
  Minimum spec:    1 vCPU, 512MB RAM, 1GB storage
  Recommended:     1 vCPU, 1GB RAM (DigitalOcean $4/mo, Linode $5/mo)
  OS:              Ubuntu 22.04 LTS
  Open ports:      8081/tcp (WebSocket relay)
  Node.js version: 18 or later
```

### 9.2 Install Node.js on VPS

```bash
ssh user@YOUR_VPS_IP

curl -fsSL https://deb.nodesource.com/setup_18.x | sudo -E bash -
sudo apt install -y nodejs

node --version   # should print v18.x.x or later
```

### 9.3 Upload relay server

```bash
# From your PC, in the rover-v3/ folder:
scp -r server/ user@YOUR_VPS_IP:~/msrp1/

# On VPS:
cd ~/msrp1
npm install
```

### 9.4 Open firewall

```bash
sudo ufw allow 8081/tcp
sudo ufw status   # verify rule appears
```

### 9.5 Run the relay server

```bash
# Test run (stops when you close SSH):
node cloud_relay.js

# Persistent run (keeps running after SSH closes):
npm install -g pm2
pm2 start cloud_relay.js --name rover-relay
pm2 save
pm2 startup   # follow the printed command to auto-start on reboot
```

Expected output:

```
[SERVER] MSRP-1 V3 Relay running
  Dashboard:   http://0.0.0.0:8081
  Rover WS:    ws://0.0.0.0:8081/?role=rover
  PC WS:       ws://0.0.0.0:8081/?role=pc
  Phone WS:    ws://0.0.0.0:8081/?role=phone
```

### 9.6 Configure phone dashboard to use relay

In phone/index.html, find this section and replace YOUR_VPS_IP:

```javascript
const MODE_URLS = {
  direct: 'ws://192.168.4.1/ws',
  lan:    'ws://192.168.1.100/ws',
  relay:  'wss://YOUR_VPS_IP:8081/?role=phone'   // <-- edit this
};
```

### 9.7 Relay data flow diagram

```
  PC browser                   VPS cloud_relay.js             Phone browser
  ----------                   ------------------             -------------
  connects to:                 receives role=pc               connects to:
  wss://VPS:8081/?role=pc      stores as connections.pc       wss://VPS:8081/?role=phone
                                                              stores as connections.phone
  user pushes joystick
       |
       v
  ws.send({type:"drive"...})
       |
       v                       receives from pc
                               if connections.phone:
                                 phone.send(data)
                                       |
                                       v
                               receives from phone
                                       |
                              (phone decides: BLE or WiFi)
                                       |
                         +------------+------------+
                         |                         |
                  BLE write to                WS send to
                  ESP32 RX char               192.168.4.1/ws
                         |                         |
                         +------------+------------+
                                      |
                               processCommand()
                                      |
                               taskMotorController
                                      |
                               motors move

  Telemetry travels the reverse path:
  ESP32 -> phone (BLE notify or WS message) -> VPS -> PC display
```

---

## 10. Battery Saver Mode

### What shuts down and what stays on

```
  Component        Normal mode          Battery saver mode
  ---------        -----------          ------------------
  WiFi AP          ON (150-200mA)       OFF (WiFi.mode(WIFI_OFF))
  WebSocket srv    ON                   OFF (no WiFi)
  OLED display     ON (20mA)            OFF (SSD1306_DISPLAYOFF cmd)
  Fan              ON (temp-controlled) OFF (forced LOW)
  BLE server       ON (30mA)            ON (stays active)
  INA219           ON (1mA)             ON (stays active)
  DS18B20          ON (1mA)             ON (stays active)
  Motor drivers    ON                   ON (you still drive)
  ESP32 core       ON                   ON (no deep sleep, must respond)

  TRIGGER CONDITIONS

  Manual:
    phone sends: {"type":"power","mode":"saver"}
    received via BLE or WiFi, calls g_powerMode = POWER_SAVER

  Automatic:
    taskTelemetry detects voltage < 7.0V (approx 20% charge)
    prints: [PWR] Low battery (x.xxV) -> auto battery saver
    calls:  g_powerMode = POWER_SAVER

  RECOVERY

  Wake command via BLE (only path available in saver mode):
    phone sends: {"type":"power","mode":"normal"}
    firmware calls applyPowerMode(POWER_NORMAL)
    WiFi AP restarts, OLED turns on, fan control resumes

  If BLE connection is lost in saver mode:
    motor watchdog fires after 500ms
    motors stop
    rover is stationary but still broadcasting BLE advertisements
    reconnect with phone to recover
```

### Power saver transition diagram

```
  NORMAL MODE
  WiFi ON + BLE ON + OLED ON + Fan controlled
       |                              ^
       | trigger:                     | command: {"type":"power","mode":"normal"}
       | voltage < 7.0V              | via BLE only (WiFi is off)
       | OR manual command            |
       v                              |
  BATTERY SAVER MODE
  WiFi OFF + BLE ON + OLED OFF + Fan OFF
  current draw: ~30-50mA (not counting motors)
```

---

## 11. Communication Protocol Reference

All messages are UTF-8 JSON strings. The same format is used on both BLE
and WiFi transports. There is no binary framing.

### Commands (phone/PC to ESP32)

```
  Drive:
  {"type":"drive","left":180,"right":180}
    left:  -255 to 255  (negative = reverse, 0 = brake)
    right: -255 to 255
    Must be sent continuously at 100ms intervals.
    Motor watchdog stops motors if no command for 500ms.

  Stop (immediate brake):
  {"type":"stop"}
    Sets both motors to active brake immediately.
    Resets watchdog timer.

  Power mode:
  {"type":"power","mode":"saver"}
  {"type":"power","mode":"normal"}

  Ping (latency check):
  {"type":"ping"}
    ESP32 replies: {"type":"pong"}
    on the same transport the ping arrived on.
```

### Telemetry (ESP32 to phone/PC, every 100ms)

```json
{
  "type":      "telem",
  "v":         7.82,
  "mA":        340,
  "mW":        2659,
  "temp":      31.5,
  "fan":       false,
  "wifiCl":    1,
  "ble":       true,
  "transport": "ble",
  "power":     "normal"
}
```

```
  Field        Type     Range/values          Meaning
  -----        ----     ------------          -------
  v            float    6.0 - 8.4             Battery voltage in Volts
  mA           float    0 - 3200*             Current draw in milliamps
  mW           float    0 - ~26000*           Power in milliwatts
  temp         float    -10 to 80             Electronics temp in Celsius
  fan          bool     true/false            Fan currently on
  wifiCl       int      0 - N                 Connected WiFi WebSocket clients
  ble          bool     true/false            BLE client connected
  transport    string   "ble"/"wifi"/"none"   Transport of last drive command
  power        string   "normal"/"saver"      Current power mode

  * INA219 saturates at 3200mA. Under heavy motor load readings clip at this
    value. This is a hardware limitation of the 0.1Ohm onboard shunt resistor.
    To fix: replace shunt with 0.01Ohm for 10x range (soldering required).
```

### BLE characteristics

```
  Service UUID:  6E400001-B5A3-F393-E0A9-E50E24DCCA9E  (Nordic UART Service)

  RX characteristic: 6E400002-B5A3-F393-E0A9-E50E24DCCA9E
    Phone WRITES commands here.
    Properties: WRITE, WRITE_NR (no response, for speed)

  TX characteristic: 6E400003-B5A3-F393-E0A9-E50E24DCCA9E
    ESP32 sends telemetry here via NOTIFY.
    Phone must subscribe to notifications on connect.
    Properties: NOTIFY

  MTU: NimBLE negotiates with the phone automatically.
  Typical result: 247 bytes MTU on Android Chrome.
  Telemetry JSON is ~150 bytes, safely under limit.
```

---

## 12. Build and Test Sequence

Build in this order. Do not proceed to the next step until the current
step passes. Each step has a specific, observable pass/fail criterion.

```
  Step  What to build                   Pass criterion
  ----  -------------                   --------------
  1     Flash firmware, no wiring       Serial Monitor shows all [BOOT] lines
                                        No [WARN] lines (sensors not yet wired)

  2     Wire and test OLED alone        OLED shows "MSRP-1 V3 / Booting..."
        (I2C SDA SCL pullups first)     i2c_scanner shows device at 0x3C or 0x3D

  3     Wire INA219 in series           Serial Monitor shows realistic voltage
        on positive power rail          (7.x V for charged 2S pack)
                                        i2c_scanner shows device at 0x40

  4     Wire DS18B20 with pullup        Serial Monitor shows ~25-30C room temp
                                        -127C means pullup resistor missing

  5     Wire ONE motor to TB6612#1      Motor spins forward then brakes in loop
        (STBY, AIN1, AIN2, PWMA)       If it twitches: PWM not zeroed before STBY HIGH
                                        If wrong direction: swap AO1/AO2 wires

  6     Wire remaining 3 motors         All 4 motors spin same direction on "forward"
                                        command. Verify no motor runs backwards.

  7     Wire fan MOSFET                 Fan turns on when DS18B20 held in fingers
        (100R series, 10k pulldown)     (~36C). Verify fan is OFF at cold boot.

  8     Connect to ROVER-V3 WiFi        Browser at 192.168.4.1 loads dashboard
        from phone                      Telemetry updates. Joystick moves rover.
                                        Watchdog test: close browser, rover
                                        must stop within 500ms.

  9     BLE test (Chrome Android)       Transport indicator shows "BLE"
                                        Telemetry updates via BLE notify
                                        Joystick moves rover via BLE path

  10    Battery saver test              WiFi AP disappears from network list
        Press "Battery Saver" button    OLED goes dark
                                        BLE stays connected
                                        Joystick still moves rover
                                        Press "Normal": WiFi AP reappears

  11    VPS relay test (optional)       From a different network (mobile data),
                                        open relay URL in browser
                                        Telemetry updates. Joystick moves rover.
                                        Latency will be higher (50-250ms).
```

---

## 13. Fault Diagnosis

### ESP32 does not appear as a serial port

```
  Symptom: no COM port or /dev/ttyUSB0 appears when connected via USB
  Cause A: cable is charge-only (no data lines)
           Fix: try a different USB cable
  Cause B: CP2102 or CH340 driver not installed
           Fix: download driver for your OS from silabs.com or wch.cn
  Cause C: wrong USB port on a hub
           Fix: connect directly to PC USB port
```

### Upload fails with "Failed to connect to ESP32"

```
  Hold the BOOT button on ESP32 during upload.
  Release after "Connecting..." appears in Arduino IDE output.
  This manually forces bootloader mode.
```

### Motor does not move

```
  Check in order:
  1. Serial Monitor shows "Motor drivers enabled"?
       NO  --> firmware crash in setup. Add Serial.println() before each
               pinMode to find where it stops.
  2. Is STBY pin (GPIO33) HIGH after boot?
       Measure with multimeter. Should be 3.3V.
       NO  --> firmware not setting it HIGH. Check ledcWrite(0) before STBY HIGH.
  3. Is TB6612 VCC (3.3V logic supply) present?
       Measure VM pin: should equal battery voltage.
       Measure VCC pin: should be 3.3V.
  4. Does AIN1 or AIN2 toggle when command is sent?
       Measure with multimeter or oscilloscope while sending drive command.
       NO  --> pin assignment mismatch in firmware defines.
```

### INA219 reads 0V or 0mA

```
  Cause A: wired in parallel instead of series
           The current must flow THROUGH the INA219 chip (VIN+ to VIN-).
           Check: disconnect VIN- from rest of circuit and measure continuity
           from battery + through INA219 to motor driver VM.
  Cause B: VIN+ and VIN- reversed
           Fix: swap the two rails going into INA219.
  Cause C: I2C address wrong
           Run i2c_scanner. INA219 should appear at 0x40.
           If not found: check SDA SCL pullup resistors.
```

### DS18B20 reads -127C

```
  This specific value means "sensor not found on 1-Wire bus".
  Cause: 4.7k pullup resistor from GPIO4 to 3.3V is missing.
  The 1-Wire protocol requires this resistor to function.
  Without it the data line never reaches logic HIGH.
  Fix: solder 4.7k between GPIO4 and 3.3V rail.
```

### OLED shows nothing

```
  Step 1: Run i2c_scanner. Does any address appear?
           NO  --> pullup resistors on SDA/SCL are missing.
                   Add 4.7k from GPIO21 to 3.3V and GPIO22 to 3.3V.
           YES --> go to step 2.
  Step 2: Is the address 0x3C or 0x3D?
           OTHER --> wrong device (check if INA219 is on wrong address)
  Step 3: Does firmware Serial Monitor show "[BOOT] OLED OK"?
           NO, shows "[WARN] OLED not found" --> VCC not connected or
           wrong I2C address for this module variant.
```

### ESP32 resets when motors start

```
  Cause: motors pull large startup current, causing voltage sag on 5V rail,
         which browses the ESP32.
  Fix A: add 1000uF electrolytic capacitor from TB6612 VM to GND,
         physically close to the TB6612 chip.
  Fix B: add 100uF + 0.1uF on LM2596 output before ESP32 VIN.
  Fix C: check that 18AWG wire is used for motor power lines, not thinner.
```

### BLE not found in Chrome Android

```
  Step 1: Phone Bluetooth is on?
  Step 2: Chrome Android version >= 56?
  Step 3: Site permissions: Settings -> Site settings -> Bluetooth -> Allow?
  Step 4: Is ESP32 within range (~10m)?
  Step 5: Serial Monitor shows "[BOOT] BLE advertising as 'MSRP1-Rover'"?
           NO --> NimBLE-Arduino library not installed correctly.
                  Delete library folder and reinstall from Library Manager.
  Step 6: Try scanning with nRF Connect app (free, Android) to confirm
          ESP32 is visible at BLE level before testing browser.
```

### Motors run backwards on one side

```
  This is a wiring polarity issue, not a firmware issue.
  Swap the two motor wires at the TB6612 output (AO1/AO2 or BO1/BO2).
  Do not modify direction logic in firmware to compensate.
  Physical wire swap is the correct fix.
```

### Watchdog fires immediately (motors stop right after command)

```
  Cause: drive commands are sent once and not repeated.
  The firmware requires continuous drive commands every 100ms.
  The phone dashboard send loop runs every 100ms and keeps the
  watchdog satisfied. If you are writing custom control code,
  you must send {"type":"drive",...} at least every 400ms.
```

---

*-------------------------------------------------------------------------------------End-----------------------------------------------------------------------------*

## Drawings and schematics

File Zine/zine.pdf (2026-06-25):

S
C

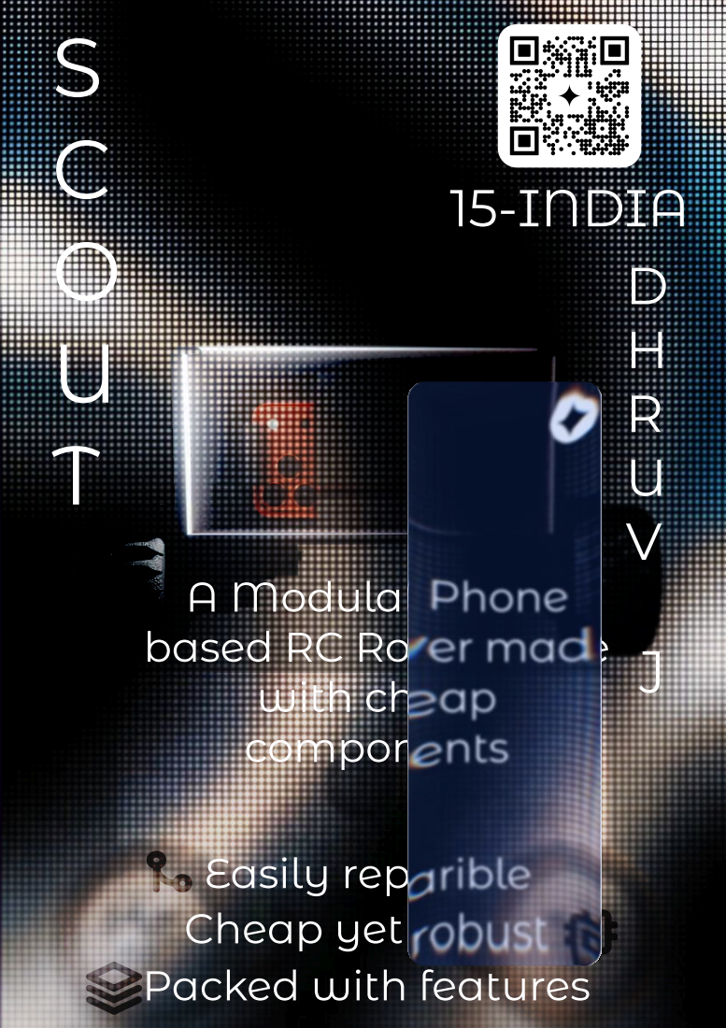
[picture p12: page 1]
15-INDIA D H R U V

A Modular Phone
based RC Rover made
with cheap
components

Easily reparible
Cheap yet robust
Packed with features

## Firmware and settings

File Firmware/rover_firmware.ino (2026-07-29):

/*
THIS CODE IS AI ASSISTED AND NOT TO BE USED PURELY FOR PROOF OF CONCEPT NOT FOR FINAL BUILD
*config
*setup
*loop
*websocket handler
*motor control
*html page for dashboard
*
 */

 #include <Wifi.h>
 #include <ESPAsyncWebServer.h>
 #include <AsyncWebsocket.h>

 const char*WIFI_SSD="SCOUT";
 const char*WIFI_PASSWORD="SCOUT123";

 #define LEFT_FORWARD 25
 #define LEFT_BACKWARD 26
 #define LEFT_SPEED 27

 #define LEFT_REAR_FORWARD 14
 #define LEFT_REAR_BACKWARD 12
 #define LEFT_REAR_SPEED 13

#define RIGHT_FORWARD  32   
#define RIGHT_BACKWARD 2    
#define RIGHT_SPEED    23   

#define RIGHT_REAR_FORWARD  19   
#define RIGHT_REAR_BACKWARD 5    
#define RIGHT_REAR_SPEED    18   


#define STBY_PIN 33

// Current motor speeds (like variables that change)
int leftSpeed = 0;    // -255 to +255 (negative = reverse)
int rightSpeed = 0;   // -255 to +255

// Web server and WebSocket objects
AsyncWebServer server(80);        // HTTP server on port 80
AsyncWebSocket ws("/ws");         // WebSocket at /ws

void setup(){
  Serial.begin(115200);
  Serial.println();
  Serial.println("Booting...");

  pinMode(LEFT_FORWARD, OUTPUT);
  pinMode(LEFT_BACKWARD, OUTPUT);
  pinMode(LEFT_SPEED, OUTPUT);
  
  pinMode(LEFT_REAR_FORWARD, OUTPUT);
  pinMode(LEFT_REAR_BACKWARD, OUTPUT);
  pinMode(LEFT_REAR_SPEED, OUTPUT);
  
  pinMode(RIGHT_FORWARD, OUTPUT);
  pinMode(RIGHT_BACKWARD, OUTPUT);
  pinMode(RIGHT_SPEED, OUTPUT);
  
  pinMode(RIGHT_REAR_FORWARD, OUTPUT);
  pinMode(RIGHT_REAR_BACKWARD, OUTPUT);
  pinMode(RIGHT_REAR_SPEED, OUTPUT);
  
  pinMode(STBY_PIN, OUTPUT);
  
  // Enable motors (STBY HIGH = motors on)
  digitalWrite(STBY_PIN, HIGH);
  Serial.println("[OK] Motors ready");

  // ── 2. Set up PWM for motor speed ──
  // This is like setting up a dimmer switch for the motors
  ledcSetup(0, 5000, 8);    // Channel 0, 5kHz, 8-bit (0-255)
  ledcAttachPin(LEFT_SPEED, 0);
  
  ledcSetup(1, 5000, 8);
  ledcAttachPin(LEFT_REAR_SPEED, 1);
  
  ledcSetup(2, 5000, 8);
  ledcAttachPin(RIGHT_SPEED, 2);
  
  ledcSetup(3, 5000, 8);
  ledcAttachPin(RIGHT_REAR_SPEED, 3);

  WiFi.mode(WIFI_AP);
  WiFi.softAP(WIFI_SSID, WIFI_PASSWORD);
  Serial.print("[OK] WiFi started: ");
  Serial.println(WIFI_SSID);
  Serial.print("     IP Address: ");
  Serial.println(WiFi.softAPIP());

  // ── 4. Set up WebSocket (for joystick) ──
  ws.onEvent(onWebSocketEvent);
  server.addHandler(&ws);

  // ── 5. Serve the HTML page ──
  // This is like sending index.html when someone visits
  server.on("/", HTTP_GET, [](AsyncWebServerRequest* request) {
    request->send_P(200, "text/html", INDEX_HTML);
  });

  server.begin();
  Serial.println("Web server has started");
  Serial.println("     Open browser to: http://192.168.4.1");
  Serial.println("=== SCOUT ROVER READY ===");
}

void loop(){
  ws.cleanupClients();
  delay(10);
}

void setMotors(int left, int right) {
  // ── LEFT MOTORS ──
  if (left > 0) {
    // Forward
    digitalWrite(LEFT_FORWARD, HIGH);
    digitalWrite(LEFT_BACKWARD, LOW);
    digitalWrite(LEFT_REAR_FORWARD, HIGH);
    digitalWrite(LEFT_REAR_BACKWARD, LOW);
    ledcWrite(0, left);    // Front left speed
    ledcWrite(1, left);    // Rear left speed
  } else if (left < 0) {
    // Reverse
    digitalWrite(LEFT_FORWARD, LOW);
    digitalWrite(LEFT_BACKWARD, HIGH);
    digitalWrite(LEFT_REAR_FORWARD, LOW);
    digitalWrite(LEFT_REAR_BACKWARD, HIGH);
    ledcWrite(0, -left);   // Front left speed (positive)
    ledcWrite(1, -left);   // Rear left speed (positive)
  } else {
    // Stop (brake)
    digitalWrite(LEFT_FORWARD, HIGH);
    digitalWrite(LEFT_BACKWARD, HIGH);
    digitalWrite(LEFT_REAR_FORWARD, HIGH);
    digitalWrite(LEFT_REAR_BACKWARD, HIGH);
    ledcWrite(0, 0);
    ledcWrite(1, 0);
  }

  // ── RIGHT MOTORS ──
  if (right > 0) {
    digitalWrite(RIGHT_FORWARD, HIGH);
    digitalWrite(RIGHT_BACKWARD, LOW);
    digitalWrite(RIGHT_REAR_FORWARD, HIGH);
    digitalWrite(RIGHT_REAR_BACKWARD, LOW);
    ledcWrite(2, right);
    ledcWrite(3, right);
  } else if (right < 0) {
    digitalWrite(RIGHT_FORWARD, LOW);
    digitalWrite(RIGHT_BACKWARD, HIGH);
    digitalWrite(RIGHT_REAR_FORWARD, LOW);
    digitalWrite(RIGHT_REAR_BACKWARD, HIGH);
    ledcWrite(2, -right);
    ledcWrite(3, -right);
  } else {
    digitalWrite(RIGHT_FORWARD, HIGH);
    digitalWrite(RIGHT_BACKWARD, HIGH);
    digitalWrite(RIGHT_REAR_FORWARD, HIGH);
    digitalWrite(RIGHT_REAR_BACKWARD, HIGH);
    ledcWrite(2, 0);
    ledcWrite(3, 0);
  }
}
void setMotors(int left, int right) {
  // ── LEFT MOTORS ──
  if (left > 0) {
    // Forward
    digitalWrite(LEFT_FORWARD, HIGH);
    digitalWrite(LEFT_BACKWARD, LOW);
    digitalWrite(LEFT_REAR_FORWARD, HIGH);
    digitalWrite(LEFT_REAR_BACKWARD, LOW);
    ledcWrite(0, left);    // Front left speed
    ledcWrite(1, left);    // Rear left speed
  } else if (left < 0) {
    // Reverse
    digitalWrite(LEFT_FORWARD, LOW);
    digitalWrite(LEFT_BACKWARD, HIGH);
    digitalWrite(LEFT_REAR_FORWARD, LOW);
    digitalWrite(LEFT_REAR_BACKWARD, HIGH);
    ledcWrite(0, -left);   // Front left speed (positive)
    ledcWrite(1, -left);   // Rear left speed (positive)
  } else {
    // Stop (brake)
    digitalWrite(LEFT_FORWARD, HIGH);
    digitalWrite(LEFT_BACKWARD, HIGH);
    digitalWrite(LEFT_REAR_FORWARD, HIGH);
    digitalWrite(LEFT_REAR_BACKWARD, HIGH);
    ledcWrite(0, 0);
    ledcWrite(1, 0);
  }

  // ── RIGHT MOTORS ──
  if (right > 0) {
    digitalWrite(RIGHT_FORWARD, HIGH);
    digitalWrite(RIGHT_BACKWARD, LOW);
    digitalWrite(RIGHT_REAR_FORWARD, HIGH);
    digitalWrite(RIGHT_REAR_BACKWARD, LOW);
    ledcWrite(2, right);
    ledcWrite(3, right);
  } else if (right < 0) {
    digitalWrite(RIGHT_FORWARD, LOW);
    digitalWrite(RIGHT_BACKWARD, HIGH);
    digitalWrite(RIGHT_REAR_FORWARD, LOW);
    digitalWrite(RIGHT_REAR_BACKWARD, HIGH);
    ledcWrite(2, -right);
    ledcWrite(3, -right);
  } else {
    digitalWrite(RIGHT_FORWARD, HIGH);
    digitalWrite(RIGHT_BACKWARD, HIGH);
    digitalWrite(RIGHT_REAR_FORWARD, HIGH);
    digitalWrite(RIGHT_REAR_BACKWARD, HIGH);
    ledcWrite(2, 0);
    ledcWrite(3, 0);
  }
}

void onWebSocketEvent(AsyncWebSocket* server, AsyncWebSocketClient* client,
                      AwsEventType type, void* arg, uint8_t* data, size_t len) {
  
  if (type == WS_EVT_DATA) {
    // When the browser sends joystick data, it comes as a string
    // Example: "200,180" means left=200, right=180
    // We need to split this into two numbers
    
    String message = String((char*)data);
    message = message.substring(0, len);  // Clean up
    
    // Find where the comma is
    int commaPos = message.indexOf(',');
    
    if (commaPos != -1) {
      // Extract left and right speeds
      String leftStr = message.substring(0, commaPos);
      String rightStr = message.substring(commaPos + 1);
      
      // Convert strings to numbers
      int left = leftStr.toInt();
      int right = rightStr.toInt();
      
      // Save the speeds
      leftSpeed = left;
      rightSpeed = right;
      
      // Apply to motors
      setMotors(leftSpeed, rightSpeed);
      
      // Debug print (you'll see this in serial monitor)
      Serial.print("Left: ");
      Serial.print(left);
      Serial.print("  Right: ");
      Serial.println(right);
    }
  }
}

const char INDEX_HTML[] PROGMEM = R"rawliteral(
<!DOCTYPE html>
<html>
<head>
  <meta charset="UTF-8">
  <meta name="viewport" content="width=device-width, initial-scale=1.0, user-scalable=no">
  <title>Scout Rover</title>
  <style>
    /* ── CSS (You already know this!) ── */
    * { box-sizing: border-box; margin: 0; padding: 0; }
    body {
      background: #0a0a0a;
      color: #00ff88;
      font-family: 'Courier New', monospace;
      display: flex;
      flex-direction: column;
      align-items: center;
      justify-content: center;
      min-height: 100vh;
      padding: 20px;
      gap: 20px;
    }
    h1 {
      color: #00ff88;
      font-size: 2rem;
      letter-spacing: 4px;
      text-shadow: 0 0 20px #00ff8840;
    }
    .status {
      font-size: 0.8rem;
      color: #555;
    }
    .status.connected {
      color: #00ff88;
    }
    
    /* Joystick */
    .joy-wrap {
      position: relative;
      width: 200px;
      height: 200px;
      touch-action: none;
    }
    .joy-base {
      width: 200px;
      height: 200px;
      border-radius: 50%;
      background: #1a1a2e;
      border: 2px solid #00ff88;
      box-shadow: 0 0 40px #00ff8820;
    }
    .joy-thumb {
      position: absolute;
      width: 60px;
      height: 60px;
      background: #00ff88;
      border-radius: 50%;
      top: 70px;
      left: 70px;
      cursor: grab;
      box-shadow: 0 0 30px #00ff8860;
      transition: background 0.1s;
    }
    .joy-thumb:active {
      background: #00cc66;
      cursor: grabbing;
    }
    
    .controls {
      display: flex;
      gap: 30px;
      align-items: center;
      flex-wrap: wrap;
      justify-content: center;
    }
    button {
      background: #1a1a2e;
      border: 1px solid #00ff88;
      color: #00ff88;
      padding: 12px 24px;
      border-radius: 8px;
      cursor: pointer;
      font-family: inherit;
      font-size: 1rem;
      transition: all 0.2s;
    }
    button:active {
      background: #00ff8833;
    }
    .stop-btn {
      border-color: #ff4444;
      color: #ff4444;
    }
    .stop-btn:active {
      background: #ff444433;
    }
    small {
      color: #555;
      font-size: 0.7rem;
    }
    #telemetry {
      display: grid;
      grid-template-columns: repeat(4, 1fr);
      gap: 10px;
      width: 100%;
      max-width: 400px;
    }
    .tcard {
      background: #1a1a2e;
      border: 1px solid #333;
      border-radius: 8px;
      padding: 10px;
      text-align: center;
    }
    .tcard .label {
      font-size: 0.6rem;
      color: #555;
      text-transform: uppercase;
    }
    .tcard .value {
      font-size: 1.1rem;
      color: #00ff88;
      font-weight: bold;
    }
  </style>
</head>
<body>

  <h1>SCOUT ROVER</h1>
  <div id="status" class="status">● Connecting...</div>

  <div id="telemetry">
    <div class="tcard"><div class="label">Left</div><div class="value" id="leftVal">0</div></div>
    <div class="tcard"><div class="label">Right</div><div class="value" id="rightVal">0</div></div>
    <div class="tcard"><div class="label">Status</div><div class="value" id="statusVal">Ready</div></div>
    <div class="tcard"><div class="label">Mode</div><div class="value" id="modeVal">WiFi</div></div>
  </div>

  <div class="controls">
    <div class="joy-wrap" id="joyWrap">
      <div class="joy-base"></div>
      <div class="joy-thumb" id="joyThumb"></div>
    </div>
    <div>
      <button id="stopBtn" class="stop-btn">■ STOP</button>
    </div>
  </div>

  <small>Connect to WiFi: ROVER-V3 | Open: 192.168.4.1</small>

  <script>
  // ──────────────────────────────────────────────────────────────
  // JAVASCRIPT (You already know this!)
  // ──────────────────────────────────────────────────────────────

  let ws = null;
  let leftSpeed = 0;
  let rightSpeed = 0;

  // ── WebSocket connection ──
  function connectWebSocket() {
    // Connect to the ESP32's WebSocket
    ws = new WebSocket('ws://' + location.hostname + '/ws');
    
    ws.onopen = function() {
      document.getElementById('status').textContent = '● Connected';
      document.getElementById('status').className = 'status connected';
      document.getElementById('statusVal').textContent = 'Online';
    };
    
    ws.onclose = function() {
      document.getElementById('status').textContent = '● Disconnected';
      document.getElementById('status').className = 'status';
      document.getElementById('statusVal').textContent = 'Offline';
      // Try to reconnect after 2 seconds
      setTimeout(connectWebSocket, 2000);
    };
    
    ws.onerror = function() {
      document.getElementById('statusVal').textContent = 'Error';
    };
  }

  // ── Send command to ESP32 ──
  function sendCommand(left, right) {
    // This sends: "left,right" as a string
    // Example: "200,180" means left=200, right=180
    if (ws && ws.readyState === WebSocket.OPEN) {
      ws.send(left + ',' + right);
      
      // Update display
      document.getElementById('leftVal').textContent = left;
      document.getElementById('rightVal').textContent = right;
    }
  }

  // ── Emergency stop ──
  function emergencyStop() {
    leftSpeed = 0;
    rightSpeed = 0;
    sendCommand(0, 0);
    document.getElementById('statusVal').textContent = 'STOPPED';
    setTimeout(function() {
      document.getElementById('statusVal').textContent = 'Ready';
    }, 1000);
  }

  // ── Joystick (touch + mouse) ──
  const wrap = document.getElementById('joyWrap');
  const thumb = document.getElementById('joyThumb');
  const MAX_RADIUS = 70;  // Max distance from center

  function handleJoyMove(cx, cy) {
    // Get joystick center position
    const rect = wrap.getBoundingClientRect();
    const centerX = rect.left + rect.width / 2;
    const centerY = rect.top + rect.height / 2;
    
    // Calculate distance from center
    let dx = cx - centerX;
    let dy = cy - centerY;
    let dist = Math.sqrt(dx*dx + dy*dy);
    
    // Limit to joystick radius
    if (dist > MAX_RADIUS) {
      dx = dx / dist * MAX_RADIUS;
      dy = dy / dist * MAX_RADIUS;
      dist = MAX_RADIUS;
    }
    
    // Move thumb
    thumb.style.transform = 'translate(' + dx + 'px, ' + dy + 'px)';
    
    // Calculate motor speeds
    // y: up = forward, down = backward
    // x: left = turn left, right = turn right
    const maxSpeed = 200;
    let forward = -dy / MAX_RADIUS;  // -1 to +1
    let turn = dx / MAX_RADIUS;      // -1 to +1
    
    // Differential steering (tank drive)
    let left = Math.round((forward + turn) * maxSpeed);
    let right = Math.round((forward - turn) * maxSpeed);
    
    // Limit to valid range
    left = Math.max(-maxSpeed, Math.min(maxSpeed, left));
    right = Math.max(-maxSpeed, Math.min(maxSpeed, right));
    
    // Send command
    sendCommand(left, right);
  }

  function handleJoyRelease() {
    thumb.style.transform = 'translate(0, 0)';
    sendCommand(0, 0);
  }

  // ── Touch events ──
  wrap.addEventListener('touchstart', function(e) {
    e.preventDefault();
    const touch = e.touches[0];
    handleJoyMove(touch.clientX, touch.clientY);
  }, {passive: false});

  wrap.addEventListener('touchmove', function(e) {
    e.preventDefault();
    const touch = e.touches[0];
    handleJoyMove(touch.clientX, touch.clientY);
  }, {passive: false});

  wrap.addEventListener('touchend', function(e) {
    e.preventDefault();
    handleJoyRelease();
  }, {passive: false});

  wrap.addEventListener('touchcancel', function(e) {
    e.preventDefault();
    handleJoyRelease();
  }, {passive: false});

  // ── Mouse events (for desktop testing) ──
  let isDragging = false;

  wrap.addEventListener('mousedown', function(e) {
    isDragging = true;
    handleJoyMove(e.clientX, e.clientY);
  });

  document.addEventListener('mousemove', function(e) {
    if (isDragging) {
      handleJoyMove(e.clientX, e.clientY);
    }
  });

  document.addEventListener('mouseup', function() {
    if (isDragging) {
      isDragging = false;
      handleJoyRelease();
    }
  });

  // ── Stop button ──
  document.getElementById('stopBtn').addEventListener('click', emergencyStop);

  // ── Connect when page loads ──
  connectWebSocket();
  </script>
</body>
</html>
)rawliteral";

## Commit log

2026-06-21 Add initial readme for PCB project
2026-06-24 Update print statement from 'Hello' to 'Goodbye'
2026-06-24 Rename Screenshot 2026-06-24 152214.png to 3D printing parts
2026-06-24 Add readme for 3D print STL files
2026-06-24 Enhance README with comprehensive project details
    Expanded the README with detailed project goals, specifications, mechanical and electrical specs, BOM, control interfaces, and safety features.
2026-06-25 Update README with important notes and specifications
    Added important note about AI-generated content and updated specifications for materials and components.
2026-06-26 Revise SCOUT description and remove outdated sections
    Updated the description of SCOUT, clarified the phone's role, and improved connectivity statement. Removed outdated sections on power distribution and build instructions for clarity.
2026-06-26 Rename Finalized BOM (1).xlsx to BOM.xlsx
    [BOM.xlsx]
2026-06-26 Rename Finalized BOM - Sheet1 (1).csv to BOM.csv
    [BOM.csv]
2026-07-29 Revise assembly instructions in README
    Updated section title from 'How to build it' to 'Assembly instructions' and added instructions for gathering components and 3D printing parts.
2026-08-07 Update BOM with USD prices and salvage notes
    Added USD prices to BOM and noted salvageable components.
2026-08-07 Add USD prices and format adjustments to BOM.csv
    Updated BOM.csv to include price in USD and adjusted formatting.
    [BOM.csv]
2026-08-07 Revise BOM.csv with updated item information
    Updated BOM.csv with new links and corrected item details.
    [BOM.csv]
2026-08-07 Update BOM.csv with new entries and total
2026-08-07 Modify BOM.csv with new components and pricing
    Updated BOM.csv to reflect new items and prices.
    [BOM.csv]
2026-11-05 Update assembly instructions in README
    Added reference to final CAD design for assembly.
